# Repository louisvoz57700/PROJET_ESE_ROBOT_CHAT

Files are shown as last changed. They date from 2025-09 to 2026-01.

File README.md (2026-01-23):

# 🤖 PROJET_ESE_ROBOT_CHAT

Bienvenue dans le repository de notre projet de 3ème année.  
Ce projet a pour but de concevoir et développer un **robot intelligent** capable d’interagir et d’échanger de manière autonome dans le cadre du jeu "Chat".  

---

## 👥 Membres de l’équipe

- [Louis Vozzola](https://github.com/louisvoz57700)  
- [Antoine LEMARIGNIER](https://github.com/LEMARIGNIER-Antoine)  
- [Thomas TERLINDEN](https://github.com/TTrld)
- [Kenny Saint Fleur](https://github.com/Kennystflr)  

---

## 📁 Structure du projet

Ce dépôt est organisé de la manière suivante :

- `Datasheet/` : Contient les **documents techniques** des composants électroniques (datasheets, notes d’application, documents de référence).  

- `Hardware/` : Contient la **conception matérielle**, incluant les projets KiCad (schémas, PCB, librairies locales) et fichiers liés à la fabrication (impression 3D).  

- `IMG/` : Contient toutes les **images et illustrations** du projet (schémas explicatifs, rendus PCB, photos du prototype, captures pour la documentation).  

- `Software/` : Contient le **code source / firmware**, y compris les projets STM32CubeIDE, le code embarqué (C/C++) et les scripts utilitaires éventuels.

---

## 📅 Organisation

- **Phase 1 (Début Septembre)** : Étude et conception
Nous avons étudié les possibilités et choisis d'adopter [deux solutions de pcb](./Hardware).
- **Phase 2 (Mi-Septembre à Mi-Octobre)** : Développement hardware & software
Nous avons réalisé le developpement hardware du projet en 3 semaines et nous avons ensuite concentré nos efforts sur le développement des blocks individuels du software embarqué.
- **Phase 3 (Décembre)** : Intégration et tests
Nous avons intégrés et adaptés les différents blocks des capteurs et actionneurs dans le [code résultant](./Software). 
- **Phase 4  (Janvier)** : Présentation finale
Malgré le dépqart en double-dipplome de la majorité de l'équipe, nous avons travaillé a obtenir des extraits vidéos montrant le résultat de nos travaux.  

---

## 🛠️ Technologies utilisées (prévisionnel)

- **Langages** : Python / C  
- **Matériel** : STM32 / VL053 / LIDAR
- **Fabrication** : JLCPCB / Imprimante 3D FDM / Fusion 360

---
## Résultats :

### Vidéo finale du chat en jeu :
https://github.com/user-attachments/assets/e0ab9da4-8b44-4d55-9d14-98a5d518202f

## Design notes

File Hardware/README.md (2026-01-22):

# 🛠️ Hardware – README

Bienvenue dans ce README dédié à **l’ensemble de la partie hardware** du projet.

---

## 🧩 Architecture matérielle

Pour notre projet, nous avons conçu **deux PCB distincts**, chacun répondant à un objectif précis :

- **[Bluetooth WB55](./WB55)**  
  Carte principale intégrant le microcontrôleur **STM32WB55** et l’ensemble de la chaîne Bluetooth Low Energy.

- **[Mainboard G431](./G431)**  
  Carte secondaire conçue comme solution de secours, destinée à prendre le relais en cas de défaillance du PCB Bluetooth.

Notre stratégie de développement s’est appuyée sur la conception d’un **module Bluetooth dédié**, incluant les éléments les plus critiques du design RF, notamment l’antenne et ses réseaux d’adaptation.  
En parallèle, par souci de robustesse et de gestion des risques, une **Mainboard alternative** a été développée pour garantir la continuité du projet.

Le module Bluetooth s’étant révélé **fonctionnel et performant dès la première mise sous tension**, nous avons validé cette architecture et décidé de **ne pas retenir la solution de repli** basée sur la Mainboard.

---

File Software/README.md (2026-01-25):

## PCB_A : version WB55 (celui sur le robot)

### Partie FreeRTOS
La section se trouve ici : [code](PCB_A/jeu_chat/PCB_BLE)

#### Fonctionnement : 
Notre code fonctionne avec FreeRTOS et nous avons décidé de le faire fonctionner grâce à 4 tâches : [disponible ici](PCB_A/jeu_chat/PCB_BLE/Core/Src/tasks)

 * task_FSM.c : c'est notre machine à état.   (attr.priority   = BASE_PRIO + 4;)
 * task_comm.c : utilisé pour l'écran, l'écran passe de l'image d'une souris à celle d'un chat suivant le mode de jeu choisis. (attr.priority   = BASE_PRIO +  1;)
 * task_control.c : mode chat, définit la façon pour attraper la souris. (Mode souris ici fonctionne, est décrite dans task_FSM, on lui fait faire seulement un carré par manque de temps). (attr.priority   = BASE_PRIO + 5;)
 * task_sensor.c : Lidar + tof ( lidar : attr.priority   = BASE_PRIO + 3; et tof : attr.priority   = BASE_PRIO + 2;)

## Organigramme de décision
Organigramme de decision

Concernant la gestion du jeu en mode souris, par manque de temps nous avons du opter pour un simple carré constituant une pattern de fuite.

### Capteurs et actionneurs : 
La logique de tous nos capteurs se retrouvent ici : [disponible ici](PCB_A/jeu_chat/PCB_BLE/Core/Src/capteurs)

Vidéo du robot suivant une cible avec le lidar :
https://github.com/user-attachments/assets/37d389ab-2c22-427e-961a-3d2abfaa119d

La logique de tous nos actionneurs se retrouvent ici : [disponible ici](PCB_A/jeu_chat/PCB_BLE/Core/Src/actionneurs)

Notre odométrie et notre PID se trouvent dans le fichier suivant : [odométrie + PID](PCB_A/jeu_chat/PCB_BLE/Core/Src/actionneurs/moteur.c)
Dans le même fichier, on y retrouvera 2 fonctions utiles à nos déplacements Robot_Translation et Robot_Rotation qui peuvent être appelées et qui nous servent pour la chasse ainsi que pour la fuite.

Test du carré sur odométrie suffisante : 
https://github.com/user-attachments/assets/7094cc9a-a563-437a-8e9e-69ce3a43d382

--- 

### Partie Bluetooth
La section Software/PCB_A/Preuve_BLE/BLE est la section de notre code de preuve de notre antenne Bluetooth intégrée à notre PCB. Tout fonctionne ! Notre code est ici :[code](PCB_A/Preuve_BLE/BLE)

Ce qu'on a fait : on a suivi la vidéo suivante : STM32 Bluetooth Firmware Tutorial (Bring-Up) - Phil's Lab #129

Les étapes : aller sur stm32CubeProgrammer et on upgrade les firmware, on n'oublie pas de start le wireless stack sinon on ne verra pas notre carte lors de la connexion bluetooth.

Puis sur stm32CubeIde, on va aller créer un service qui peut écrire et lire.

On rajoute une fonction pour interpréter les notifications (la fonction est ici : [custom_app.c](PCB_A/Preuve_BLE/BLE/STM32_WPAN/App/custom_app.c))

Rajoutons un message : "Hello Laurent Fiack from antonio, Louis, Kenny et thomas!", qu'on va lire sur notre téléphone pour tester la connexion.

Une fois que c'est fait, on installe sur notre téléphone l'application ST BLE toolbox. 

On se connecte sur notre carte :



puis on rejoins notre service : 



On regarde le message reçu :



La valeur hexadécimale affichée est : 

4865-6C6C-6F20-4C61-7572-656E-7420-4669-6163-6B20-6672-6F6D-2061-6E74-6F6E-69-6F2C-204C-6F75-69-732C-204B-656E-6E79-2065-7420-7468-6F6D-6173-2100

Ce qui donne en (ASCII) :

Hello Laurent Fiack from antonio, Louis, Kenny et thomas!

C'est bien le message envoyé !

### IHM

L'utilisation du bluetooth nous permet de créer une Interface Homme-Machine (IHM) nous permettant de communiquer avec le robot depuis une machine. Pour cela nous avons utilisée une page web [appBLEv1.0](PCB_A/Software_bluetooth/appBLEv1.0.html) qui peut tirer à profit l'extention BLE de Chrome (à date de janvier 2026 Chrome est le seul navigateur où cette extention existe).

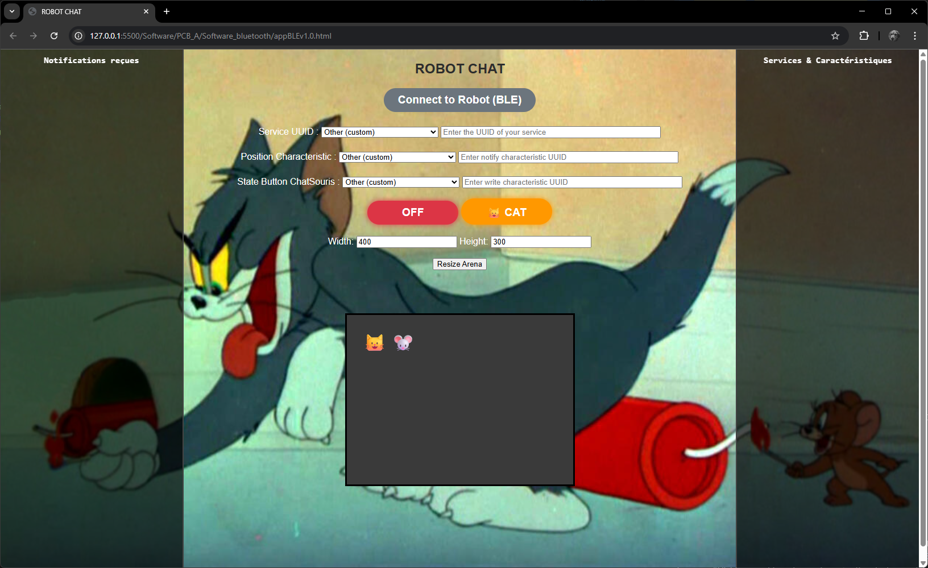
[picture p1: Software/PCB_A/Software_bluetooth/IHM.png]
IHM


Cette page html permet de se connecter au robot, d'envoyer des commandes (démarrer/arrêter, choisir le mode chat/souris) en utilisant la caractéristique écrire et de recevoir des informations (odometrie du robot et position du robot adverse) en utilisant la caractéristique notify.

Pour utiliser cette page, il suffit de l'ouvrir dans Chrome. Avant de connecter la stm32, il bien indiquer l'uuid du service, vous pourrez retrouver cette information avec l'application ST BLE toolbox comme montré dans la section précédente ou sur PC avec le logiciel [Bluetooth LE Explorer](https://apps.microsoft.com/detail/9n0ztkf1qd98) de Microsoft. 
La page web est faite de façon à ce que l'uuid du service et des caractéristiques soient modifiables et vous pouurez retrouver les uuids des services lors de la connexion.

Le projet [ble_demo](PCB_A/ble_demo) est un exemple d'utilisation de l'interface bluetooth permettant une demonstration simple de l'IHM et des caractéristiques bluetooth implémentées.

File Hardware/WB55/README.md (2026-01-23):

## 📡 PCB Bluetooth

Pour cette carte électronique, nous avons privilégié l’utilisation des composants recommandés et fournis par notre professeur, afin d’assurer **fiabilité et cohérence pédagogique**.  

Les principaux composants intégrés sont :

- **Microcontrôleur** :  
  *STM32WB55CGU*, intégrant un second cœur **Cortex-M0+** dédié à la gestion de la communication **Bluetooth Low Energy (BLE)**.

- **Drivers moteurs** :  
  *ZXBM5210*, permettant un pilotage simple et efficace des moteurs.

- **Régulateur LDO (5 V → 3,3 V)** :  
  *BU33SD5WG-TR*, utilisé pour l’alimentation du microcontrôleur.

- **Convertisseur Buck (Vbat → 5 V)** :  
  *MP1475SGJ-P*, destiné à l’alimentation des capteurs (LiDAR, ToF, mesure de courant).

- **Multiplexeur I²C** :  
  *TCA9548AMRGER*, permettant de sélectionner dynamiquement le capteur ToF avec lequel communiquer.

- **Accéléromètre** :  
  *ADXL343*, utilisé pour la détection des taps et des mouvements.

---
## Schéma de Principe


---

## 🔹 Description du PCB Bluetooth

### Section RF
La **partie droite du PCB** est dédiée à la **section RF**, avec notamment :

- Une **antenne conçue et réalisée directement sur le PCB**.  
- Un **filtre passe-bande centré sur 2,4 GHz**.  
- Un **réseau d’adaptation d’impédance** pour optimiser les performances radio et le débit maximal.

### Connecteur Bluetooth externe
Un **connecteur dédié au Bluetooth externe** permet de disposer d’une **solution de secours** si le module intégré ne fonctionne pas ou ne répond pas aux performances attendues, augmentant ainsi la **robustesse et la flexibilité** du système.

### Capteurs et moteurs
Le PCB intègre **quatre connecteurs pour les capteurs ToF**, pour détecter les obstacles à l’avant, à l’arrière et sur les côtés du robot.  
Les **deux sorties moteurs** et les **signaux des encodeurs** sont regroupés sur le **côté gauche**, facilitant l’intégration mécanique et optimisant le **routage des câbles**.

### Indicateurs de tension
Des **indicateurs 3,3 V et 5 V** permettent de vérifier rapidement le bon fonctionnement des régulateurs et simplifient les phases de **mise au point et de diagnostic**.

### Test points et conversion de tension
- La **partie droite** regroupe les **points de test**, donnant accès aux signaux principaux pour le **débogage**.  
- La **conversion de tension** est placée sur l’**autre face du PCB** (côté « chat-souris »), isolant les étages de puissance des circuits sensibles et améliorant la **lisibilité globale** de la carte.

---
## Réalisation :

<p align="center">
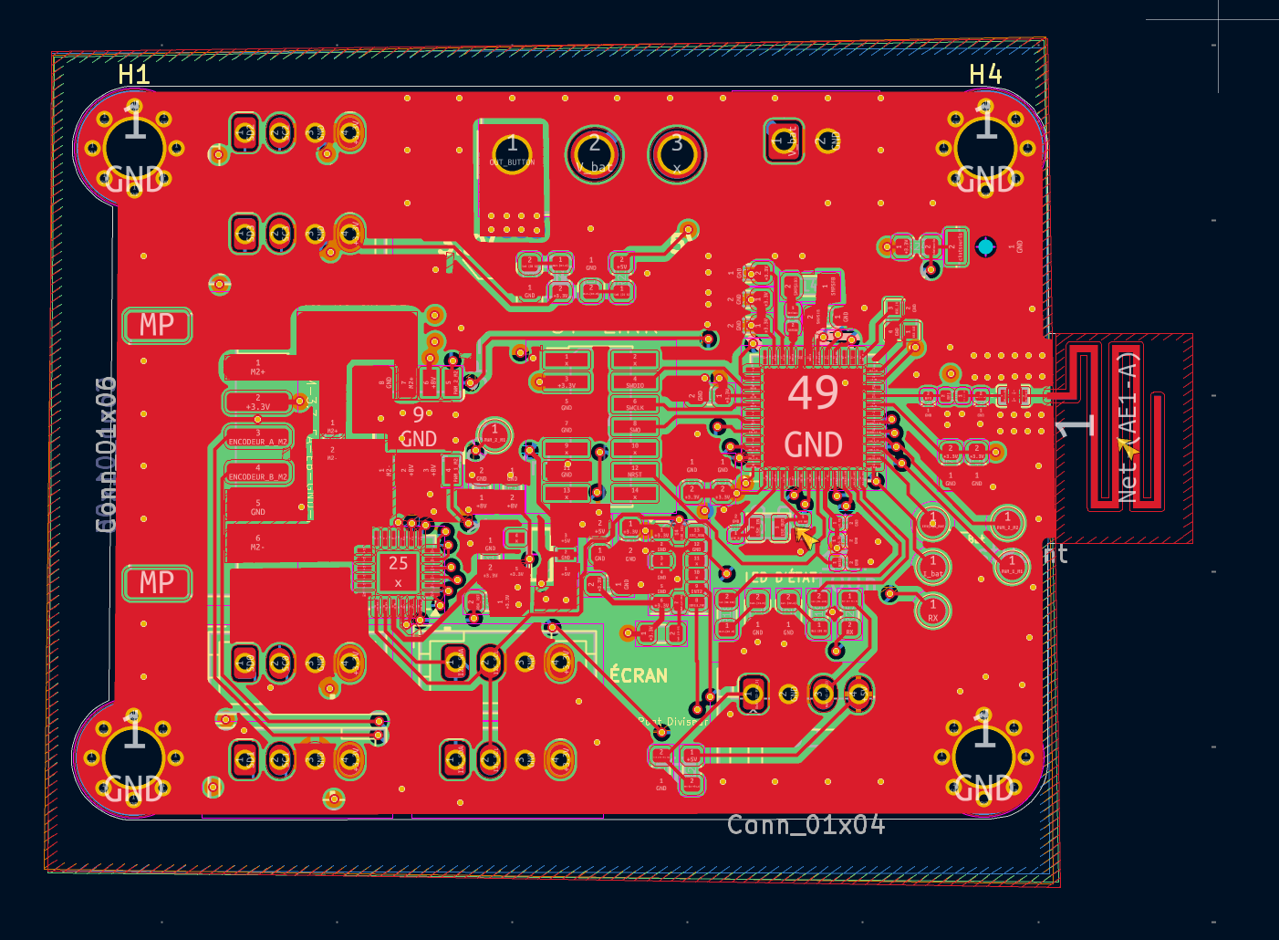
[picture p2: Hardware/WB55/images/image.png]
  
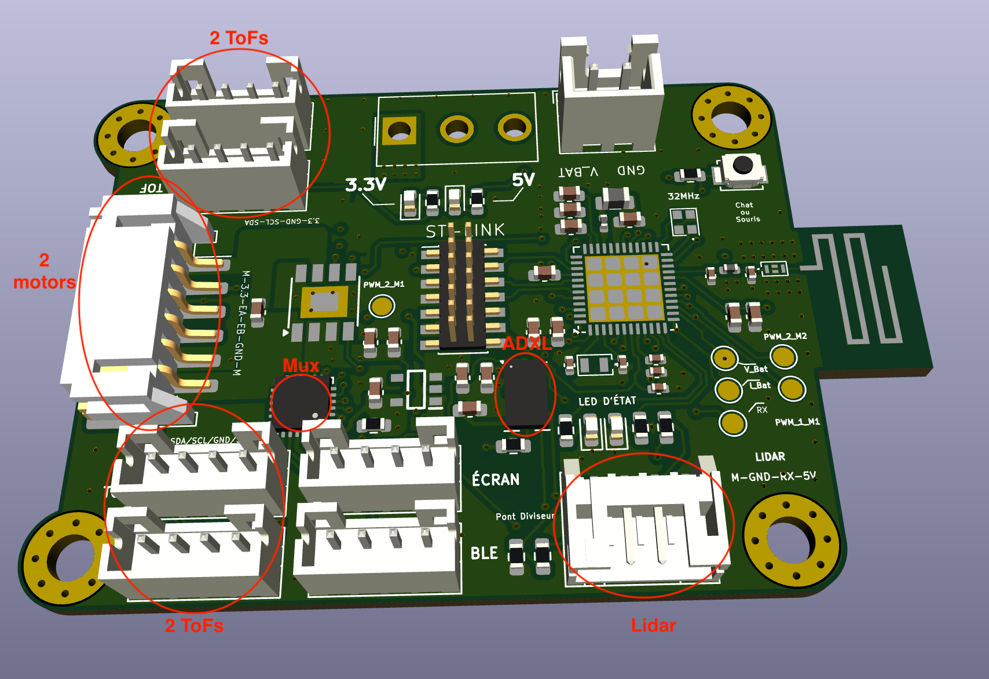
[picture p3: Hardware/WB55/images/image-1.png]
  
  
</p>

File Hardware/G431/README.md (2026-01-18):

# 🤖 Robot Chat – Carte électronique de contrôle  
## Version alternative (non embarquée sur le robot final)

## Présentation générale

Ce dépôt présente une **carte électronique de contrôle** développée dans le cadre du projet **Robot Chat**, réalisé au sein de la spécialité **ESE**.

⚠️ **Note importante**  
Le PCB documenté ici correspond à une **version alternative de la carte électronique**, différente de celle effectivement intégrée sur le robot final.  
Cette version a été conçue afin d’explorer une **architecture plus modulaire et plus riche en périphériques**, tout en respectant les mêmes contraintes fonctionnelles et temporelles que la carte embarquée.

La carte a été **entièrement conçue, routée et préparée à la validation en 4 semaines**, couvrant l’ensemble de la chaîne électronique du système robotique.

---

## 🖼️ Vue d’ensemble du PCB

### Vue 3D
> *Implantation globale des composants et contraintes mécaniques*

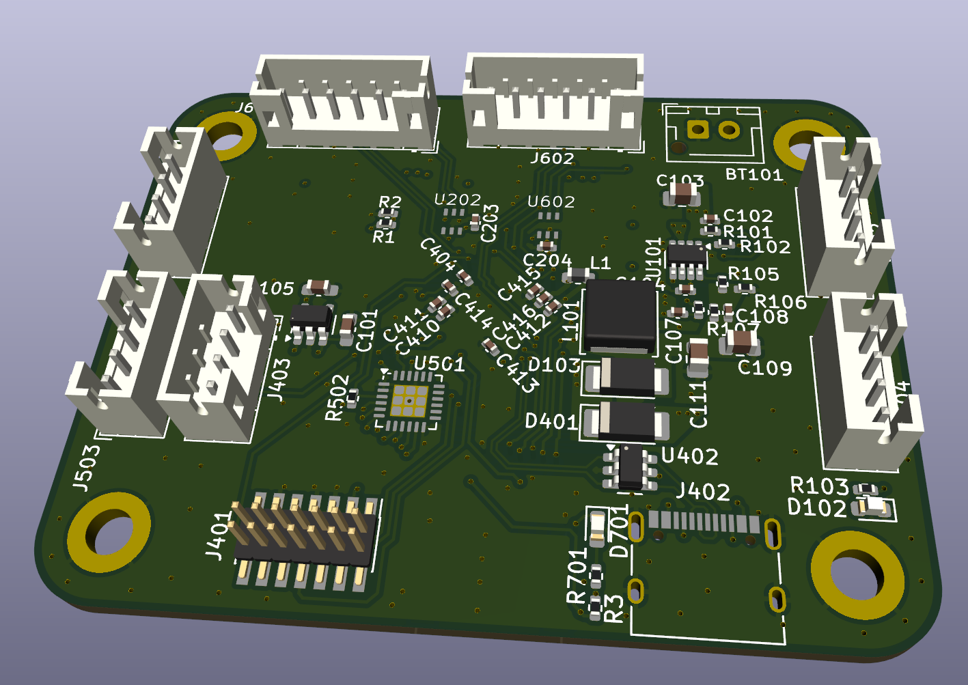
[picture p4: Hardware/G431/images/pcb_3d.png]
Vue 3D du PCB


### Faces Top & Bottom
> *Placement des composants, densité de routage et organisation des plans*

| Face Top | Face Bottom |
|---|---|
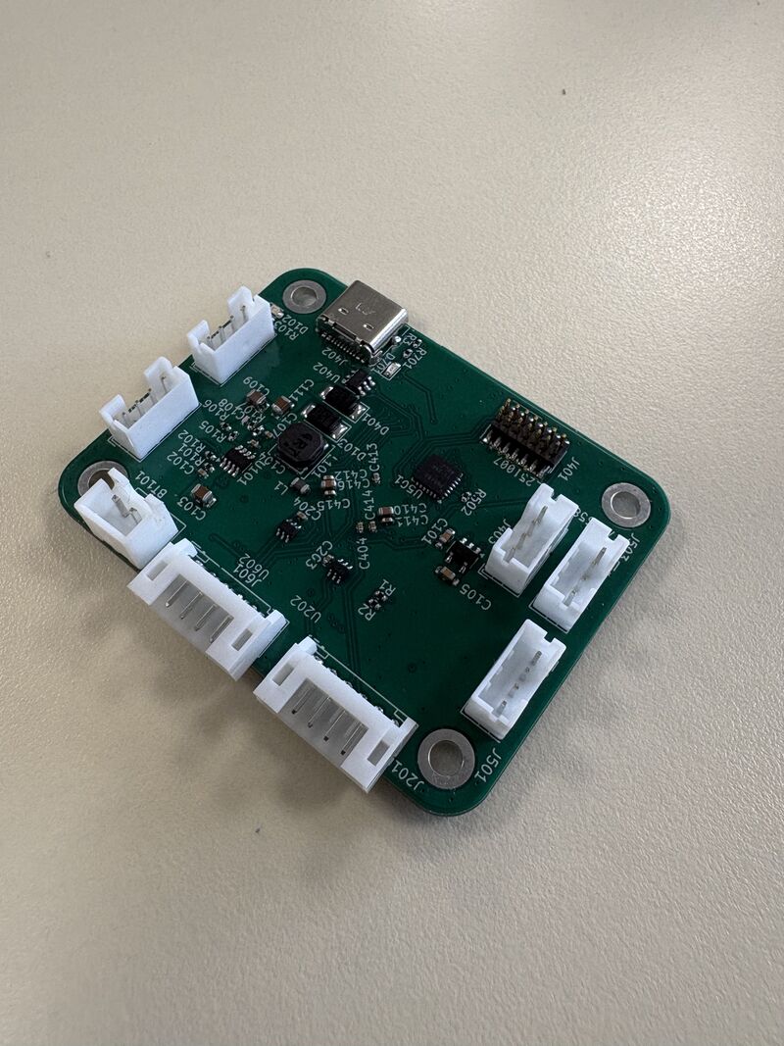
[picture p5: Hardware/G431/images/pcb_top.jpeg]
PCB Face Top
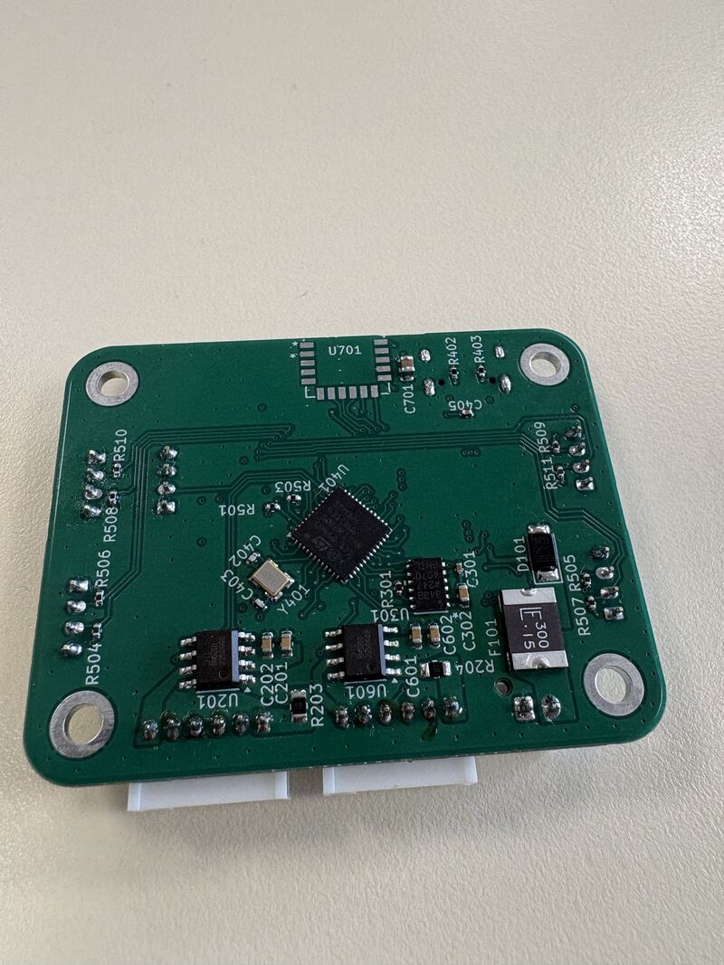
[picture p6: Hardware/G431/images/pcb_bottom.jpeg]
PCB Face Bottom
|  |  |

📌 Ces visuels permettent une lecture rapide de la complexité de la carte et de sa qualité de conception.

---

## 🧠 Architecture système

### Schematic Globale
> *Vue haut niveau des sous-systèmes et des flux de données*

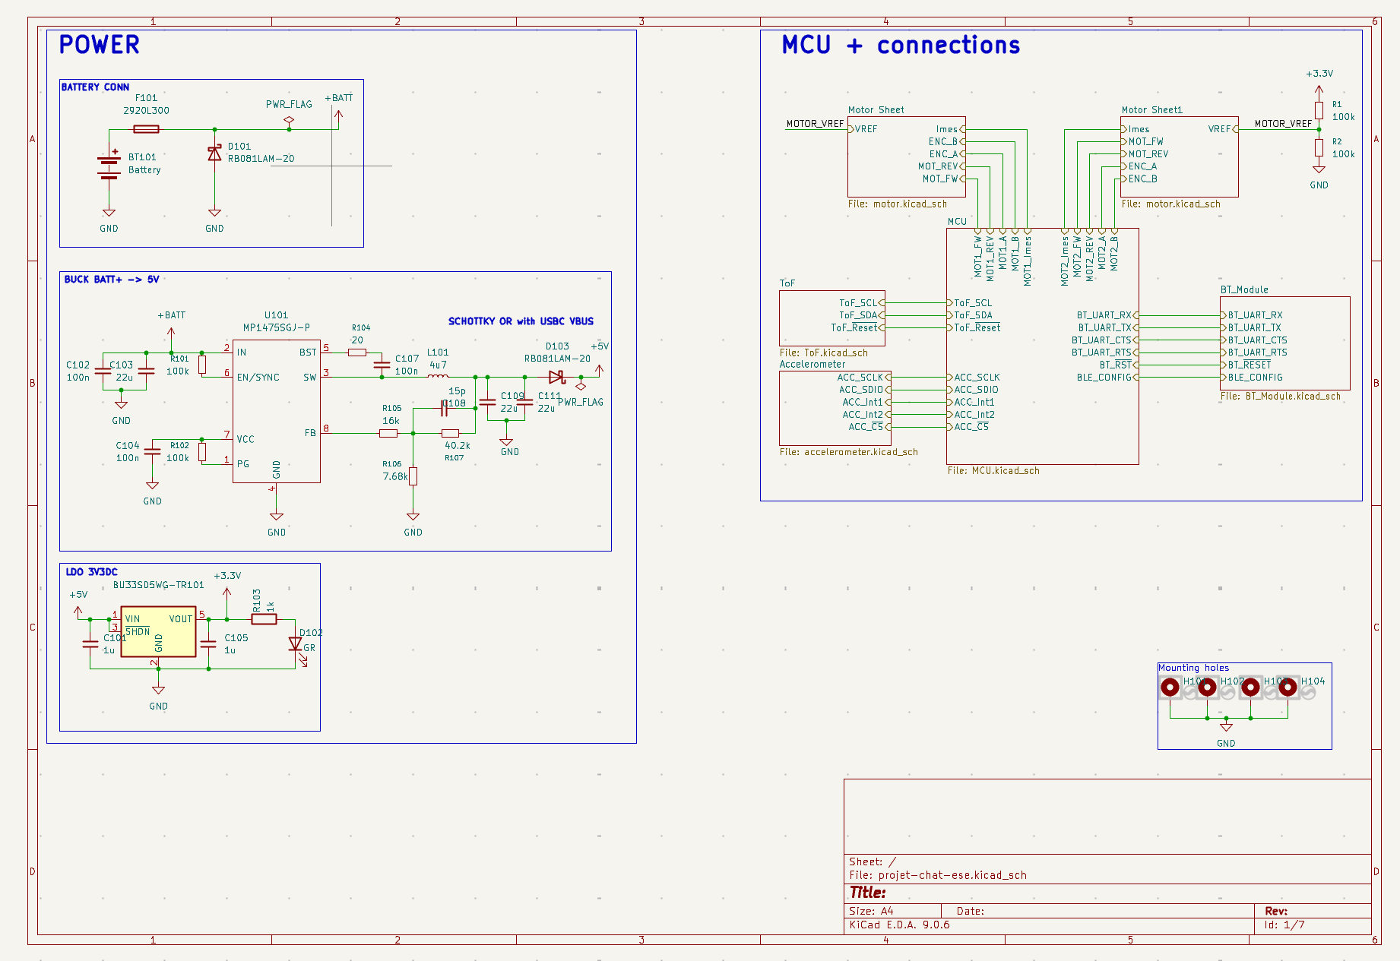
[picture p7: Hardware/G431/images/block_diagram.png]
Schema fonctionnel


La carte est organisée autour des blocs fonctionnels suivants :
- calcul et traitement temps réel,
- commande des actionneurs,
- acquisition des capteurs,
- gestion de l’alimentation.

---

## 🔌 Calcul & communication

### Microcontrôleur principal

- **STM32G431 – 170 MHz**
  - Exécution de **FreeRTOS**
  - Gestion du contrôle moteur
  - Acquisition capteurs et fusion de données
  - Communication avec l’IHM PC (UART->Bluetooth)

Le microcontrôleur centralise les tâches temps réel critiques du système.

---

## ⚙️ Commande des moteurs

- **2 drivers de moteurs DC**
- Lecture des **codeurs incrémentaux**
- **Mesure de courant** pour :
  - estimation du couple,
  - détection de surintensité,
  - sécurisation du système

L’architecture permet un contrôle précis et robuste des actionneurs.

---

## 📡 Capteurs & navigation

- **4 capteurs Time-of-Flight (ToF)**
  - détection du vide,
  - évitement d’obstacles
- **IMU (accéléromètre + gyroscope)**
  - odométrie,
  - estimation de l’état du robot
- **Lidar**
  - cartographie de l’environnement,
  - navigation autonome dans l’aire de jeu

Le placement des capteurs a été pensé pour maximiser le champ de vision et limiter les interférences.

---

## 🔋 Architecture d’alimentation

### Arbre d’alimentation
> *Stratégie de régulation et domaines de tension*

- Plusieurs rails d’alimentation régulés
- Séparation des domaines :
  - puissance moteurs,
  - logique numérique,
  - capteurs sensibles
- Filtrage et découplage adaptés à un système embarqué mobile

---

## 🧱 Conception PCB

- **PCB 4 couches**
  - Signal
  - Plan de masse continu
  - Plan d’alimentation
  - Signal
- Séparation analogique / numérique
- Routage optimisé pour :
  - intégrité du signal,
  - réduction du bruit,
  - facilité de mise au point (bring-up)

---

## 👥 Équipe & encadrement

Projet réalisé par :
- Antoine Lemarignier  
- Louis Vozzola  
- Thomas Terlinden  
- Kenny Saint Fleur

Encadrement :
- **Laurent Fiack**
- **Nicolas Papazoglou**  
École nationale supérieure de l’Électronique et de ses Applications (ENSEA)

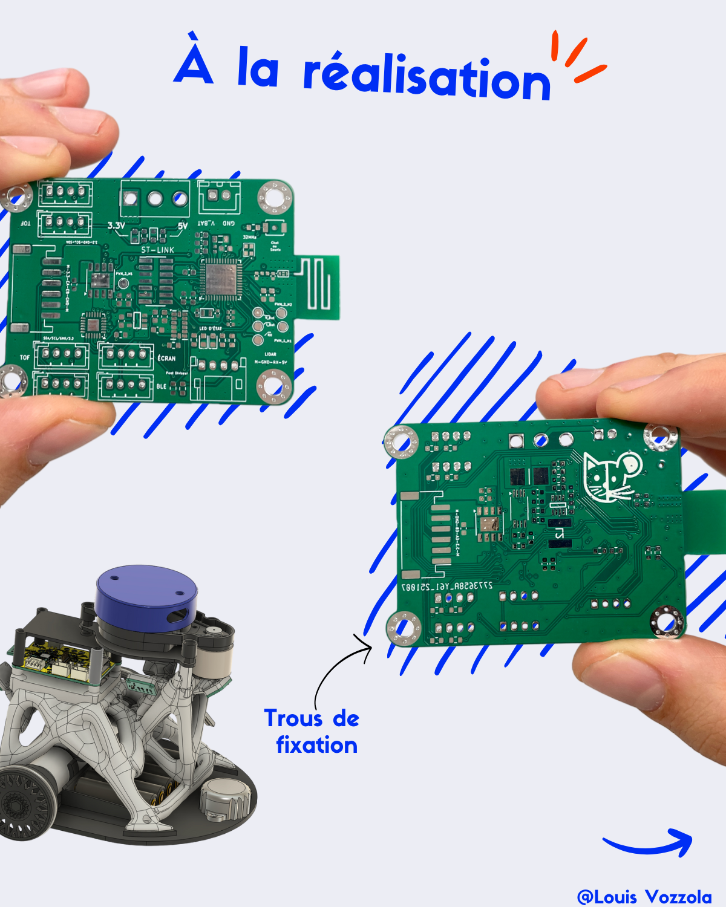
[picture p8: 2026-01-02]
IMG/PCB_BLE2.PNG

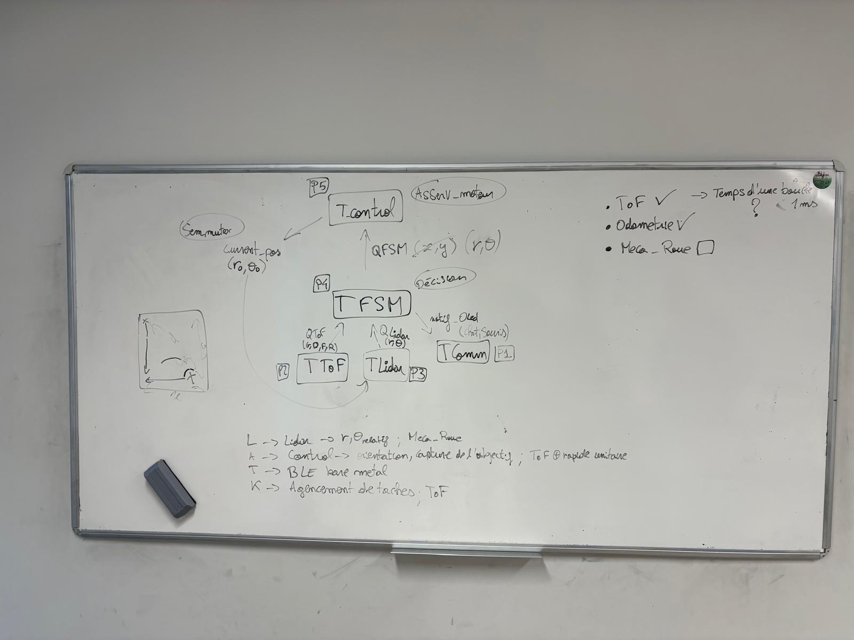
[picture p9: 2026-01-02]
IMG/Strategy.JPG

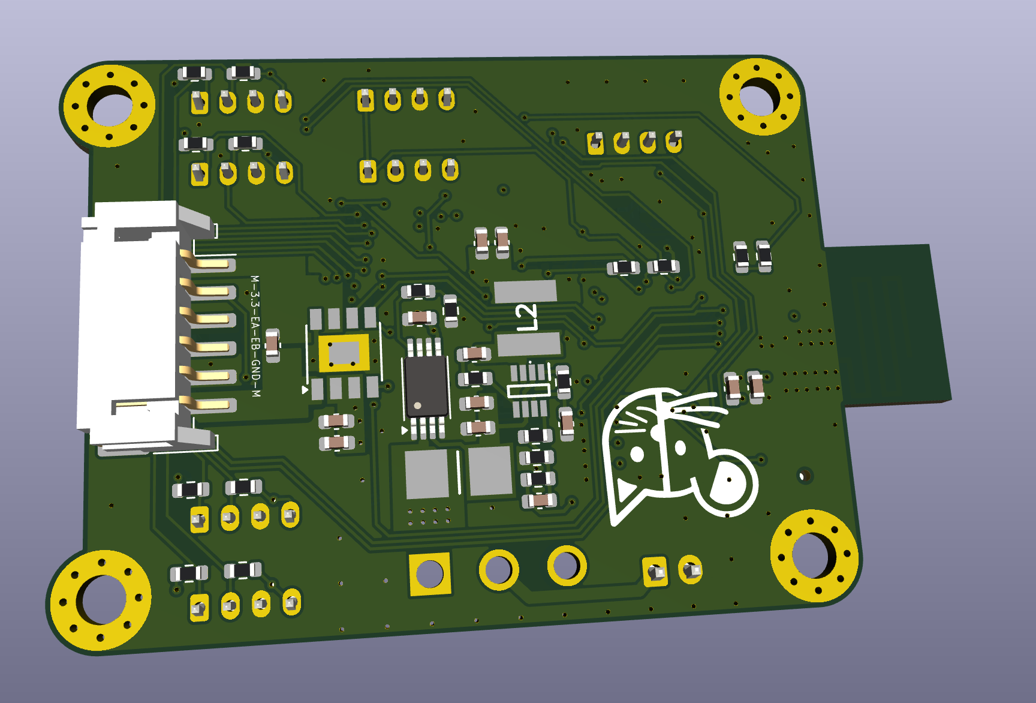
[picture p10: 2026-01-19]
IMG/PCB_BLE_Kicad_3D_Down.png

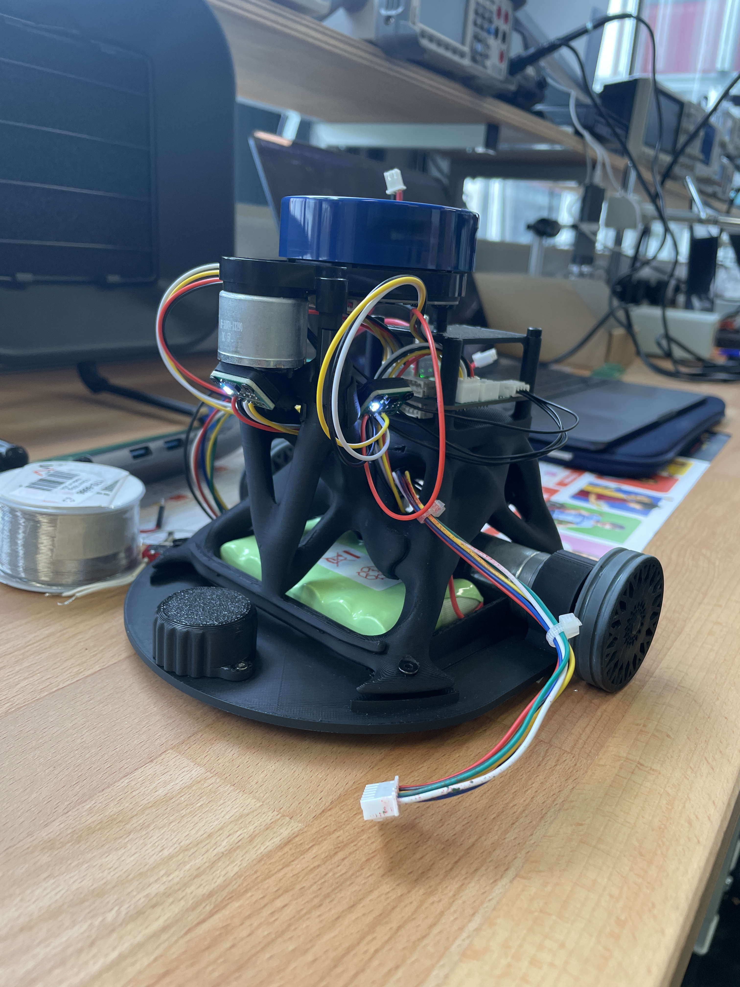
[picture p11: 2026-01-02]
IMG/robot_2.JPG

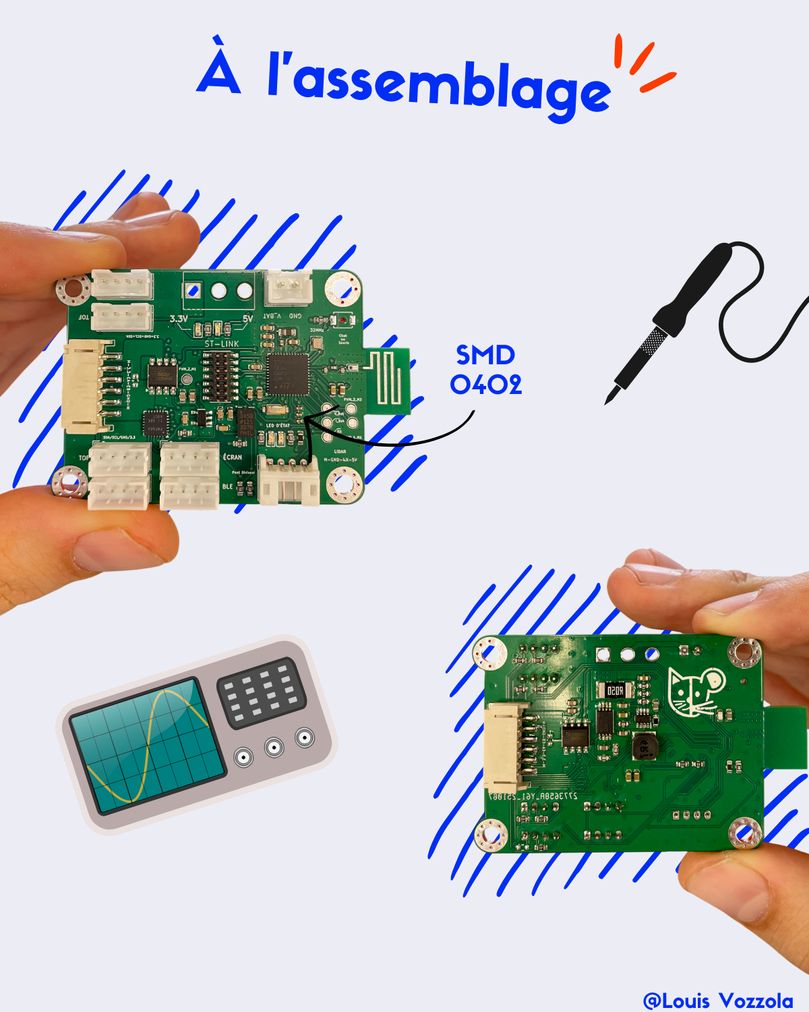
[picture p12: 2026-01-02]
IMG/PCB_BLE3.PNG

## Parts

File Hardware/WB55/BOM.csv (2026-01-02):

Id | Designator | Footprint | Quantity | Designation | Supplier and ref
1 | C43,C33,C32,C39,C12,C29,C30 | C_0603_1608Metric | 7 | 4.7u
2 | J2 | JST_PH_S4B-PH-K_1x04_P2.00mm_Horizontal | 1 | Conn_01x04
3 | AE1 | 2.4GHz BLE | 1 | Antenna
4 | J14,J11 | JST_PH_S6B-PH-SM4-TB_1x06-1MP_P2.00mm_Horizontal | 2 | Conn_01x06
5 | SW2 | SW_SPST_B3U-1000P-B | 1 | SW_SPST
6 | C1 | C_0402_1005Metric | 1 | 10n
7 | R19,R22,R23,R18,R24,R16,R17 | R_0603_1608Metric | 7 | 5k
8 | C40 | C_0402_1005Metric | 1 | 0p3
9 | C13,C14 | C_0402_1005Metric | 2 | 13p
10 | U4 | Texas_RGE0024C_VQFN-24-1EP_4x4mm_P0.5mm_EP2.1x2.1mm | 1 | TCA9548AMRGER
11 | C15,C16,C37,C31 | C_0603_1608Metric | 4 | 1u
12 | TP7,TP9,TP2,TP4,TP1,TP5 | TestPoint_Pad_D1.5mm | 6 | TestPoint
13 | C41 | C_0402_1005Metric | 1 | 0p8
14 | J9 | JST_XH_B2B-XH-A_1x02_P2.50mm_Vertical | 1 | Conn_01x02_Pin
15 | J4,J3,J8,J5,J7,J6 | JST_PH_B4B-PH-K_1x04_P2.00mm_Vertical | 6 | Conn_01x04
16 | D2,D1,D4,D3 | LED_0603_1608Metric | 4 | LED
17 | L3 | L_0402_1005Metric | 1 | 10n
18 | R26,R27,R33 | R_0603_1608Metric | 3 | 2k
19 | C8,C38,C6,C7,C11,C5,C9 | C_0603_1608Metric | 7 | 100n
20 | C2 | C_0402_1005Metric | 1 | 1u
21 | J1 | PinHeader_2x07_P1.27mm_Vertical_SMD | 1 | Conn_ST_STDC14
22 | IC4,IC3 | Diodes_SO-8EP | 2 | ZXBM5210-SP-13
23 | U5 | SSOP-5 | 1 | BU33SD5WG-TR
24 | FL1 | DLF162500LT5028A1 | 1 | DLF162500LT-5028A1
25 | R31,R30 | R_0603_1608Metric | 2 | 10k
26 | U1 | QFN-48-1EP_7x7mm_P0.5mm_EP5.6x5.6mm | 1 | STM32WB55CGUx
27 | R25 | R_0603_1608Metric | 1 | 100
28 | Y2 | Murata 32MHz | 1 | Crystal_GND24_Small
29 | C34 | C_0603_1608Metric | 1 | 470n
30 | C42 | C_0402_1005Metric | 1 | 100n
31 | L5 | L_0402_1005Metric | 1 | 2n7
32 | U3 | LGA-14_3x5mm_P0.8mm_LayoutBorder1x6y | 1 | ADXL343
33 | X1 | ABS06N32768kHzT | 1 | 32kHz758
34 | SW1 | SW_Wurth_WS-TOTV_472121020311 | 1 | SW_Wurth
35 | L4 | L_0805_2012Metric | 1 | 10u
36 | C36,C24,C22,C35,C25 | C_0603_1608Metric | 5 | 0.1u
37 | C28 | C_0603_1608Metric | 1 | 15p
38 | L2 | 74404054068 | 1 | 4.7u
39 | R11 | R_0603_1608Metric | 1 | 13k
40 | R9 | R_0603_1608Metric | 1 | 16k
41 | R2,R3,R21,R1,R5,R20,R4,R28,R6,R29 | R_0603_1608Metric | 10 | 4.7k
42 | C23,C21,C27 | C_0603_1608Metric | 3 | 22u
43 | R12 | R_0603_1608Metric | 1 | 100k
44 | C10 | C_0603_1608Metric | 1 | 100p
45 | U2 | TSSOP-8_4.4x3mm_P0.65mm | 1 | INA240A1PW
46 | IC2 | TSOT 23-8 | 1 | MP1475SGJ-P
47 | R15 | R_6431 | 1 | 50m
48 | R10 | R_0603_1608Metric | 1 | 40.2k
49 | R32 | R_0603_1608Metric | 1 | 1k
50 | R8 | R_0603_1608Metric | 1 | 20

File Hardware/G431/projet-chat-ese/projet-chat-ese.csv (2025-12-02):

Id | Référence | Empreinte | Quantité | Désignation | Fournisseur et réf
1 | C111,C103,C109 | C_0805_2012Metric | 3 | 22u
2 | U501 | VQFN-24-1EP_4x4mm_P0.5mm_EP2.45x2.45mm | 1 | TCA9548APWR
3 | J501,J503,J502,J504 | JST_PH_B4B-PH-K_1x04_P2.00mm_Vertical | 4 | Conn_01x04
4 | C204,C203,C412,C413,C102,C107,C415,C414,C411,C104,C405,C301 | C_0402_1005Metric | 12 | 100n
5 | C416,C410 | C_0402_1005Metric | 2 | 4u7
6 | J403 | JST_PH_B4B-PH-K_1x04_P2.00mm_Vertical | 1 | UART
7 | R107 | R_0402_1005Metric | 1 | 40.2k
8 | R701 | R_0402_1005Metric | 1 | 330
9 | D701 | LED_0603_1608Metric | 1 | LED
10 | L1 | L_0603_1608Metric | 1 | 39n
11 | C108 | C_0402_1005Metric | 1 | 15p
12 | R101,R102,R3,R1,R2 | R_0402_1005Metric | 5 | 100k
13 | C105,C101 | C_0603_1608Metric_Pad1.08x0.95mm_HandSolder | 2 | 1u
14 | BU33SD5WG-TR101 | SOT-23-5 | 1 | LM1117DT-3.3
15 | L101 | L_APV_ANR5020 | 1 | 4u7
16 | U202,U602 | SC70-6 | 2 | NCS199A3RSQT2G
17 | C404 | C_0402_1005Metric | 1 | 10n
18 | R104 | R_0402_1005Metric | 1 | 20
19 | J402 | USB_C_Receptacle_XKB_U262-16XN-4BVC11 | 1 | USB_C_Receptacle_USB2.0_16P
20 | J401 | PinHeader_2x07_P1.27mm_Vertical_SMD | 1 | Conn_ST_STDC14
21 | U101 | TSOT-23-8 | 1 | MP1475SGJ-P
22 | D103,D401,D101 | D_SOD-128 | 3 | RB081LAM-20
23 | R103 | R_0402_1005Metric | 1 | 1k
24 | R502,R511,R509,R508,R510,R506,R504,R501,R507,R503,R505 | R_0402_1005Metric | 11 | 4k7
25 | D102 | LED_0603_1608Metric | 1 | GR
26 | U402 | SOT-23-6 | 1 | USBLC6-2SC6
27 | R106 | R_0402_1005Metric | 1 | 7.68k
28 | BT101 | JST_XH_B2B-XH-AM_1x02_P2.50mm_Vertical | 1 | Battery
29 | J201,J601 | JST_PH_B6B-PH-K_1x06_P2.00mm_Vertical | 2 | Conn_01x06_Socket
30 | R105 | R_0402_1005Metric | 1 | 16k
31 | C402 | C_0402_1005Metric | 1 | 12p
32 | U601,U201 | SOIC-8-1EP_3.9x4.9mm_P1.27mm_EP2.29x3mm | 2 | ZXBM5210-SP-13
33 | C302,C602,C201,C601,C202 | C_0603_1608Metric | 5 | 1u
34 | Y401 | SMD 3225 | 1 | MCSJK-7U-16.00-10-30-80-B-30
35 | R204,R203 | R_0805_2012Metric | 2 | 10m
36 | U701 | BM71BLES1FC2_MCH | 1 | BM71BLES1FC2-0B04AA
37 | R403,R402 | R_0402_1005Metric | 2 | 5k1
38 | C403 | C_0402_1005Metric | 1 | 10p
39 | U301 | LGA_CC-14-1_ADI | 1 | ADXL343BCCZ-RL
40 | U401 | QFN-48-1EP_7x7mm_P0.5mm_EP5.6x5.6mm | 1 | STM32G431CBUx
41 | C701 | C_0805_2012Metric | 1 | 10u
42 | R301 | R_0402_1005Metric | 1 | 10k
43 | F101 | 2920L300 | 1 | 2920L300

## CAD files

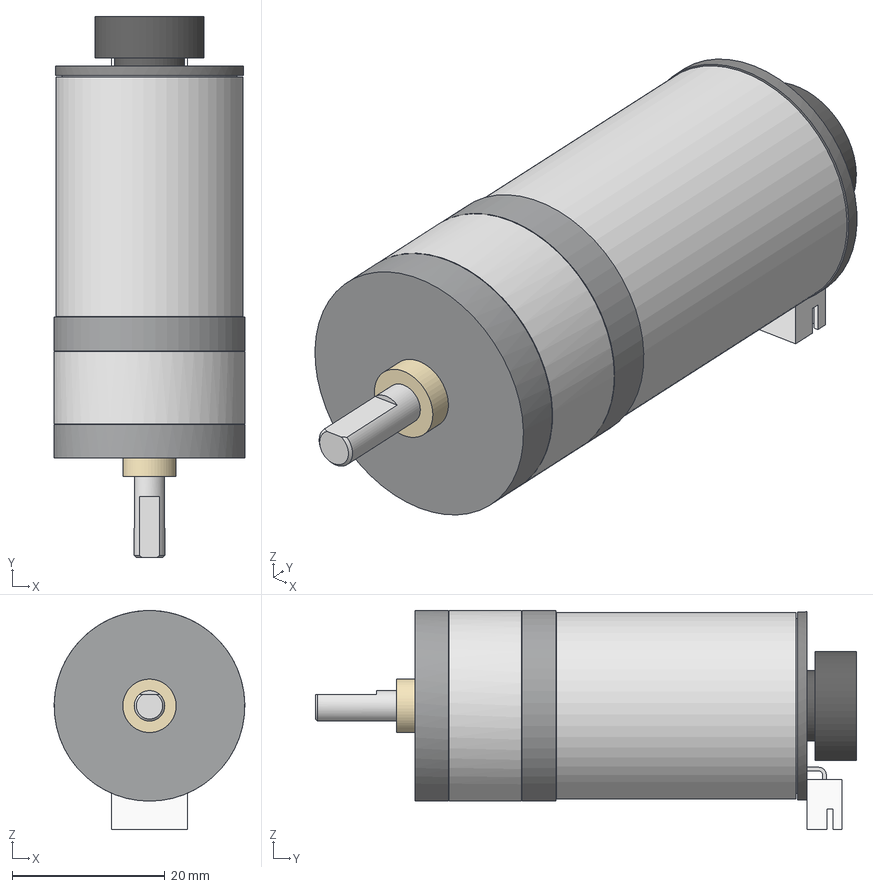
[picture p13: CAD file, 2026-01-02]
Hardware/Mecanic/FIT0520(motor).stp
25.0 x 71.0 x 28.7 mm

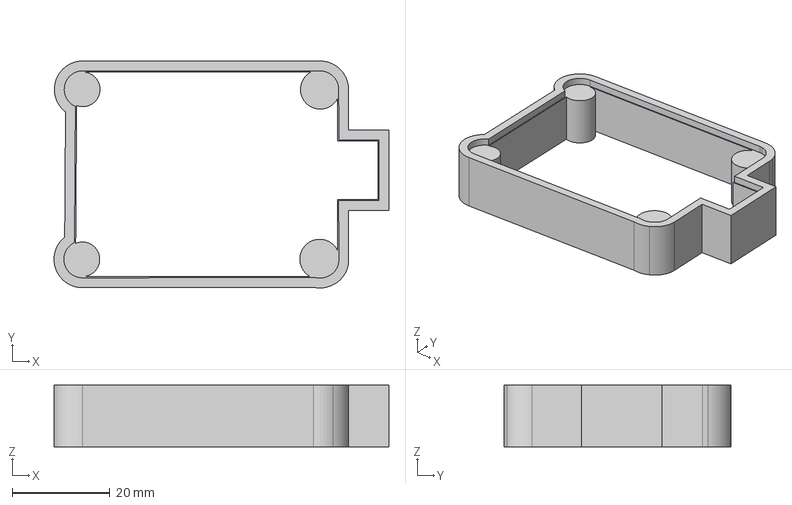
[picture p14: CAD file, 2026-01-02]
Hardware/WB55/support_PCB.step
68.5 x 46.4 x 12.6 mm

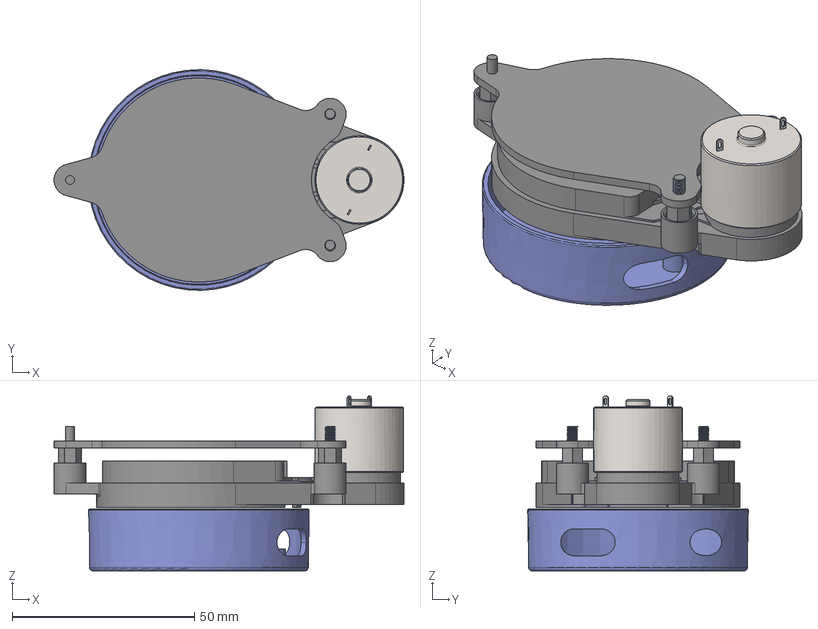
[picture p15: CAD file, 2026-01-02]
Hardware/Mecanic/LIDAR.step
96.0 x 60.5 x 48.0 mm

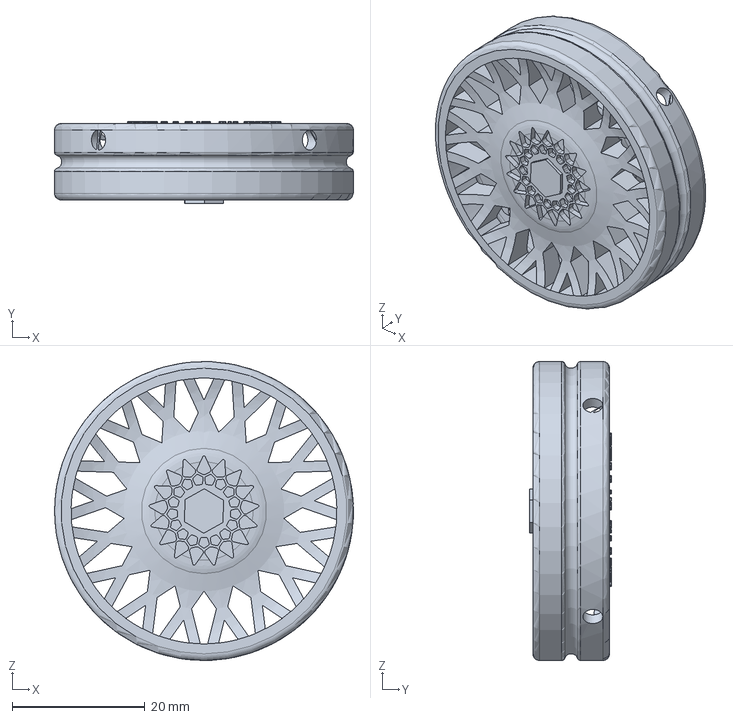
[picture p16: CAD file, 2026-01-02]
Hardware/Mecanic/wheel.step
45.0 x 12.3 x 45.0 mm

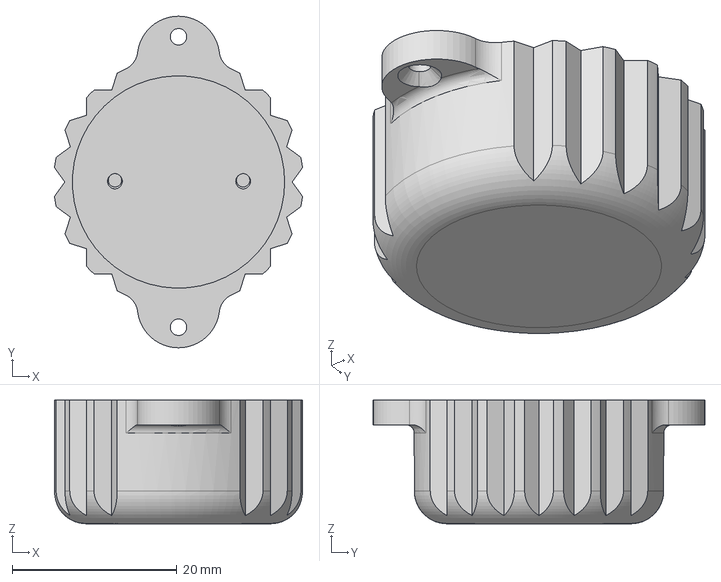
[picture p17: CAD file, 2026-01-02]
Hardware/Mecanic/bowl_support.step
30.1 x 40.2 x 15.0 mm

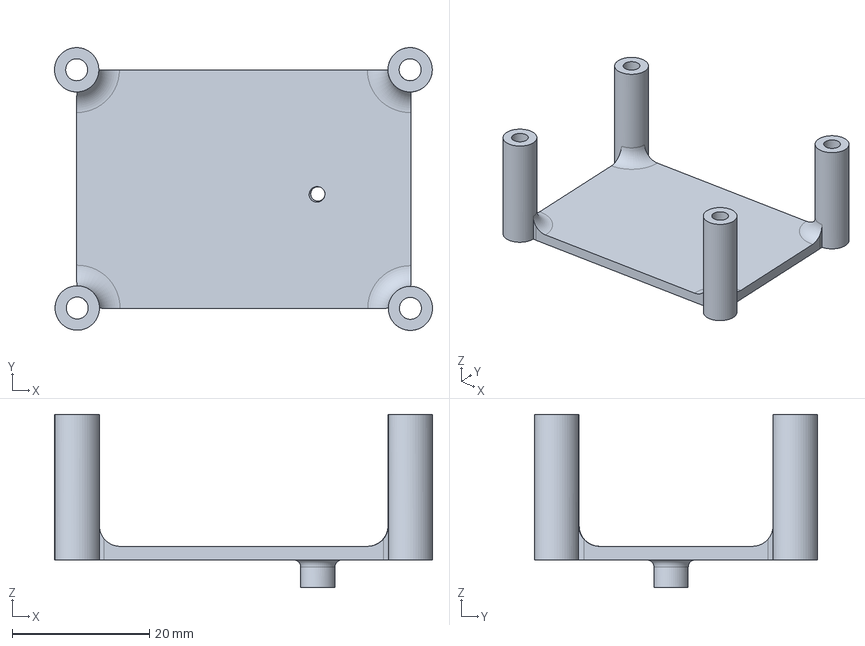
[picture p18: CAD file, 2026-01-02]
Hardware/Mecanic/up_body2.step
55.0 x 41.2 x 25.2 mm

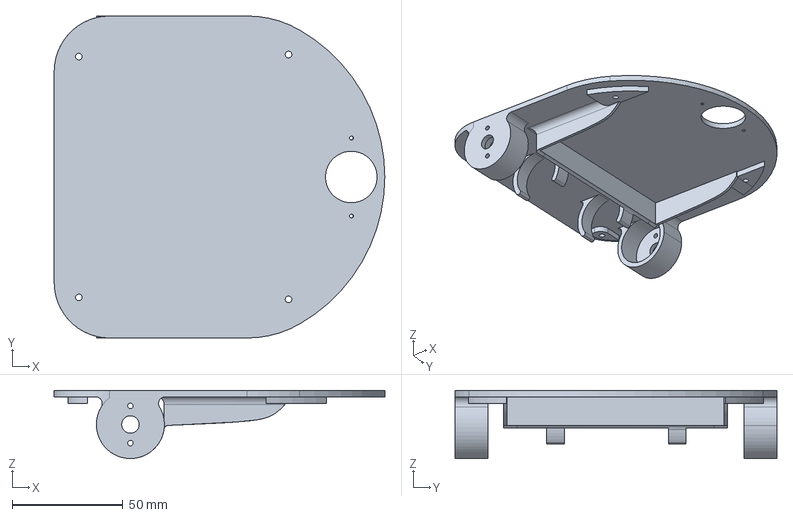
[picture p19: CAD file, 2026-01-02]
Hardware/Mecanic/down_body.step
149.2 x 145.3 x 30.7 mm

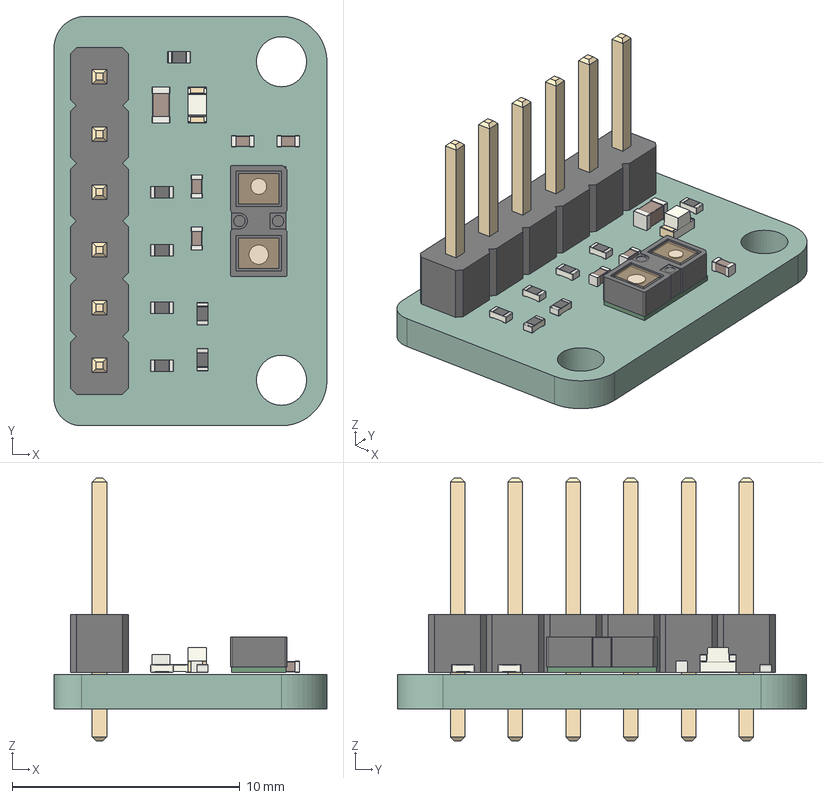
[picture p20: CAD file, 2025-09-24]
Hardware/Mecanic/vl53l0(TOF).step
12.0 x 18.0 x 11.5 mm
C_0402_1005Metric x 4
R_0402_1005Metric x 7
PinHeader_1x06_P2.54mm_Vertical
LED_0603_1608Metric
C_0603_1608Metric
ST_VL53L1x
vl53l0_breakout_PCB

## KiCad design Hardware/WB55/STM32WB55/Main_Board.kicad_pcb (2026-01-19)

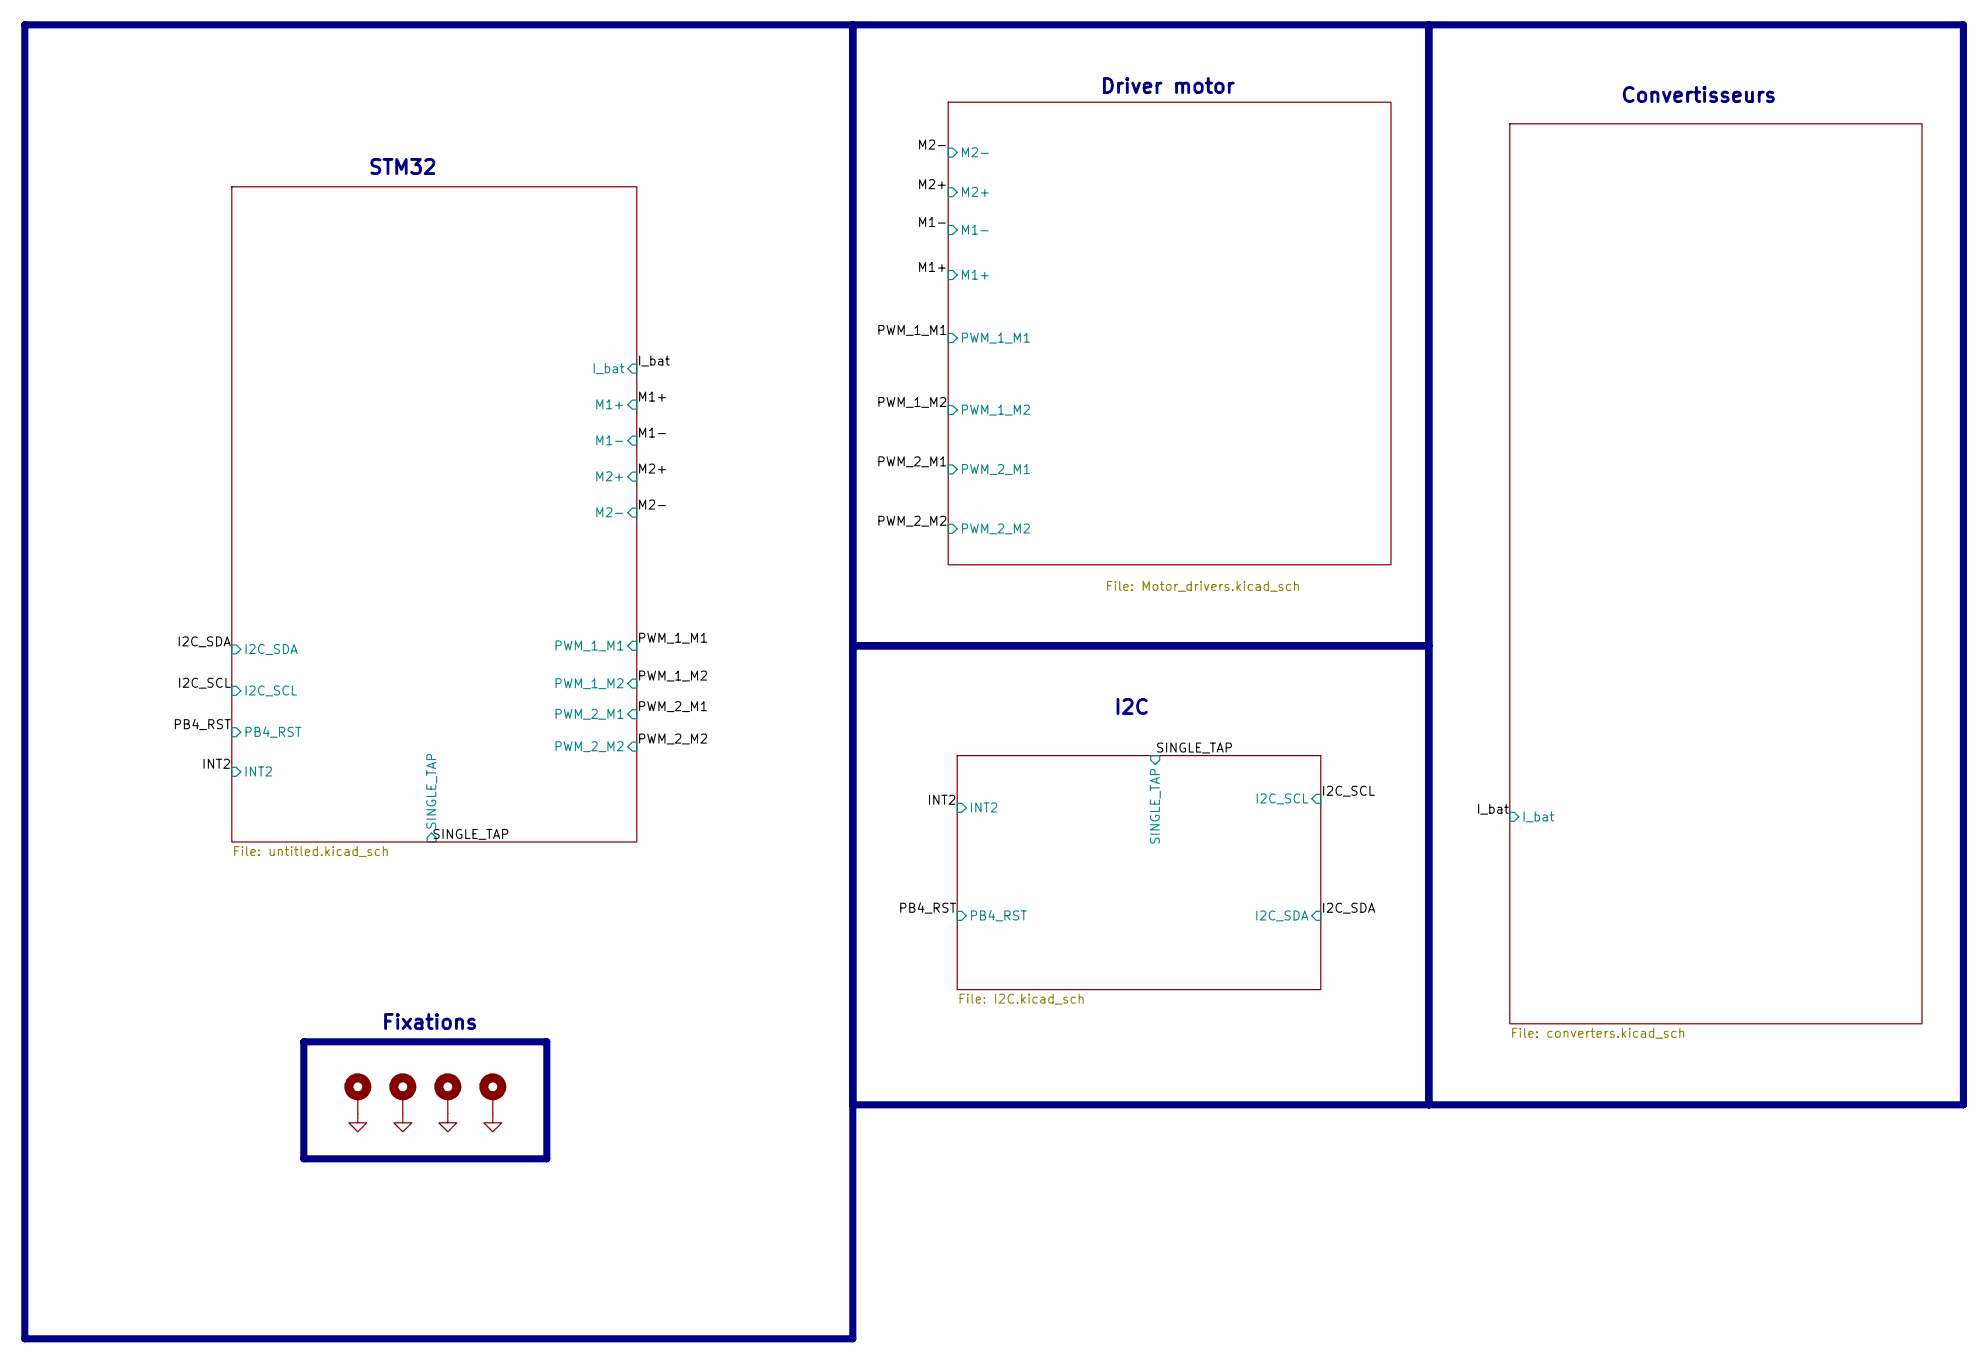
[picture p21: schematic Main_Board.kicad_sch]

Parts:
H1, H2, H3, H4: MountingHole_Pad; MountingHole_3.2mm_M3_Pad_Via

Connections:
GND: H1.1, H2.1, H3.1, H4.1; also elsewhere on the board

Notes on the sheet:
Convertisseurs
I2C
STM32
Fixations
Driver motor

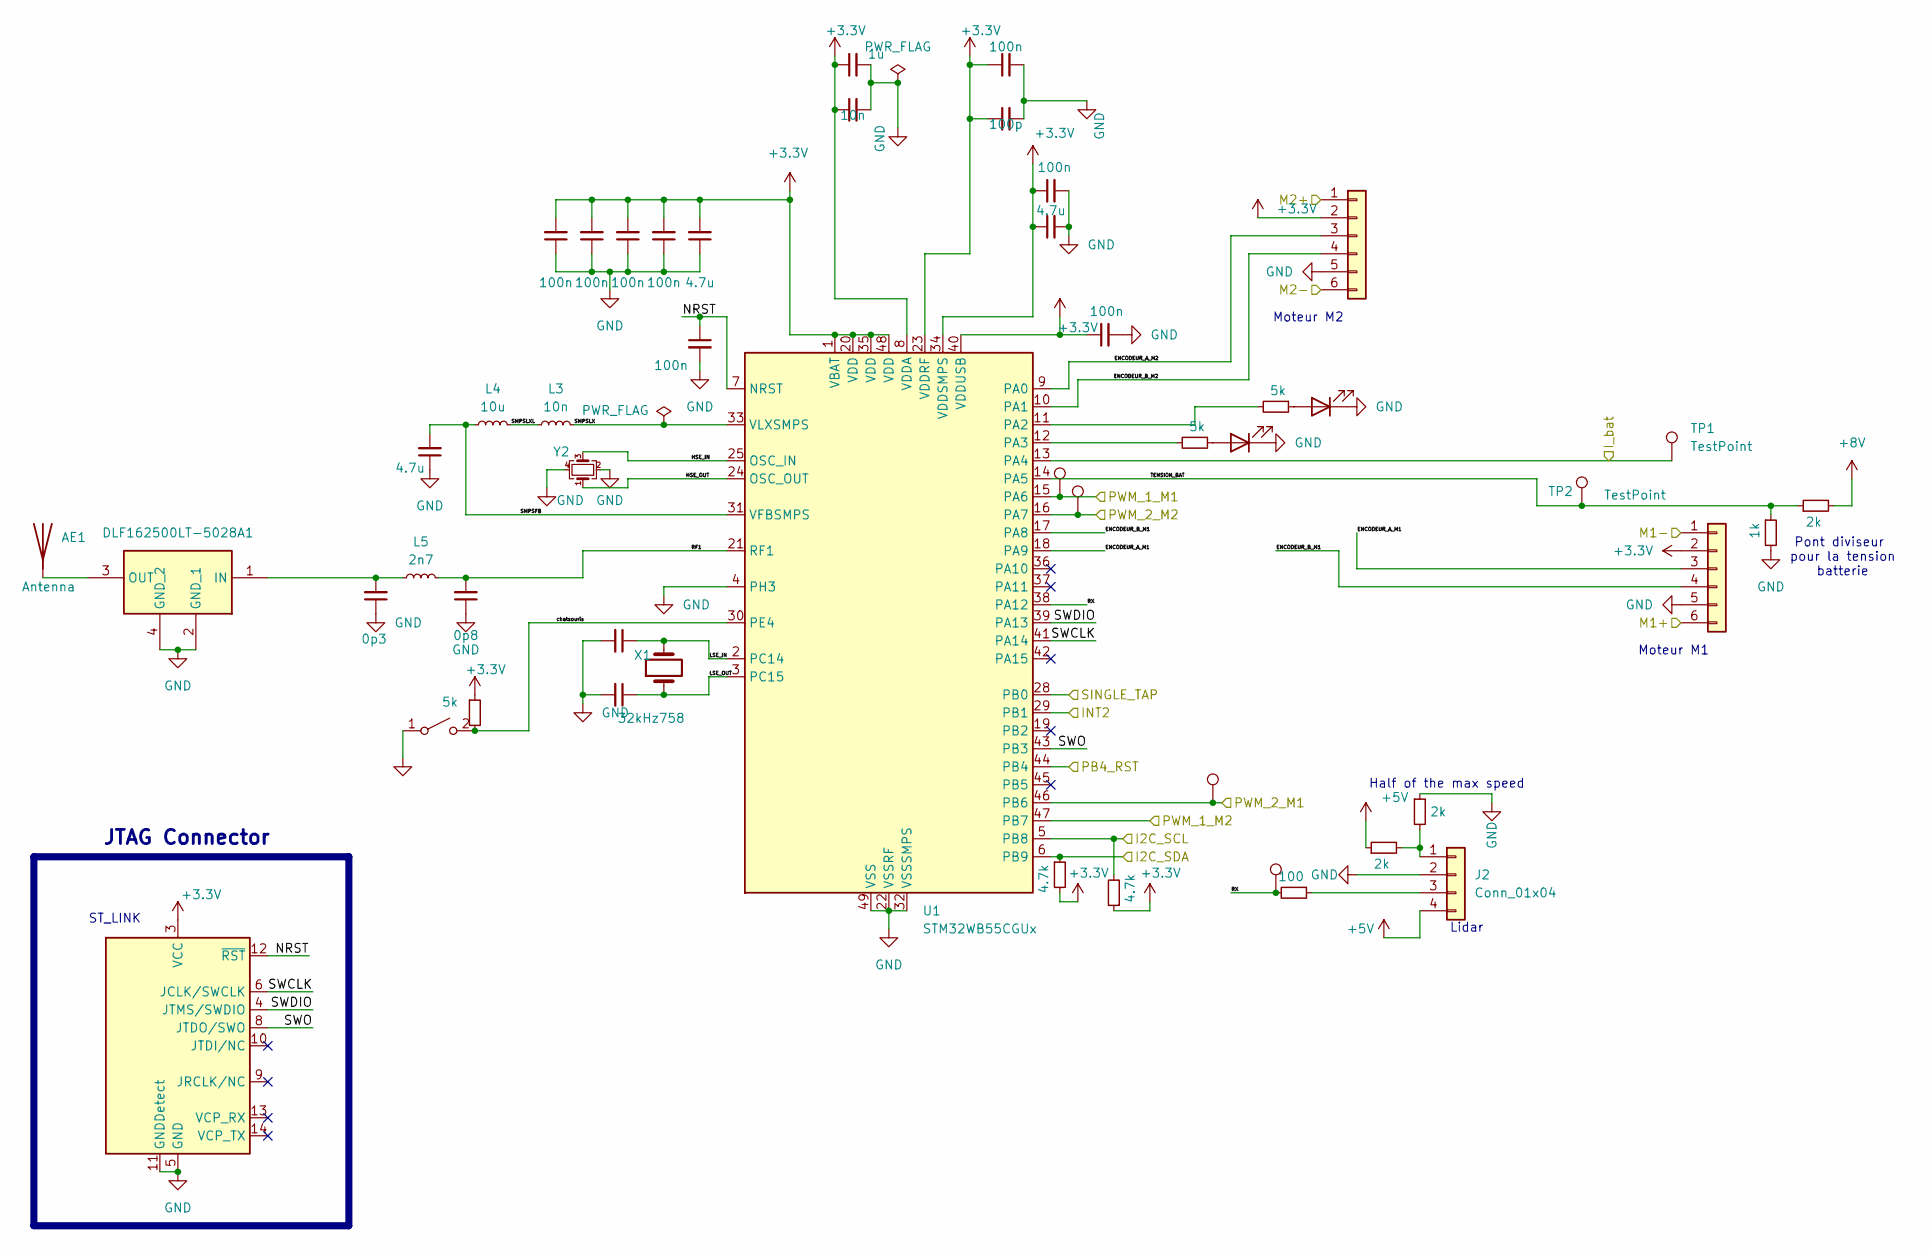
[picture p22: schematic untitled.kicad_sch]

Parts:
AE1: Antenna; 2.4GHz BLE
C1: 10n; C_0402_1005Metric
C2: 1u; C_0402_1005Metric
C5, C6, C7, C8, C9, C11, C38: 100n; C_0603_1608Metric
C10: 100p; C_0603_1608Metric
C12, C39, C43: 4.7u; C_0603_1608Metric
C13, C14: 13p; C_0402_1005Metric
C40: 0p3; C_0402_1005Metric
C41: 0p8; C_0402_1005Metric
C42: 100n; C_0402_1005Metric
D1, D2: LED; LED_0603_1608Metric
FL1: DLF162500LT-5028A1; DLF162500LT5028A1; Mouser Part Number 810-DLF16250LT5028A1
J1: Conn_ST_STDC14; PinHeader_2x07_P1.27mm_Vertical_SMD
J2: Conn_01x04; JST_PH_S4B-PH-K_1x04_P2.00mm_Horizontal
J11, J14: Conn_01x06; JST_PH_S6B-PH-SM4-TB_1x06-1MP_P2.00mm_Horizontal
L3: 10n; L_0402_1005Metric
L4: 10u; L_0805_2012Metric
L5: 2n7; L_0402_1005Metric
R18, R19, R24: 5k; R_0603_1608Metric
R25: 100; R_0603_1608Metric
R26, R27, R33: 2k; R_0603_1608Metric
R28, R29: 4.7k; R_0603_1608Metric
R32: 1k; R_0603_1608Metric
SW2: SW_SPST; SW_SPST_B3U-1000P-B
TP1, TP2, TP4, TP5, TP7, TP9: TestPoint; TestPoint_Pad_D1.5mm
U1: STM32WB55CGUx; QFN-48-1EP_7x7mm_P0.5mm_EP5.6x5.6mm
X1: 32kHz758; ABS06N32768kHzT
Y2: Crystal_GND24_Small; Murata 32MHz

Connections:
+3.3V: C1.1, C2.1, C5.2, C6.2, C7.2, C8.2, C9.1, C10.1, C11.1, C12.1, C38.1, C43.2, J1.3 (VCC), J11.2, J14.2, R24.1, R28.2, R29.1, U1.1 (VBAT), U1.8 (VDDA), U1.20 (VDD), U1.23 (VDDRF), U1.34 (VDDSMPS), U1.35 (VDD), U1.40 (VDDUSB), U1.48 (VDD); also elsewhere on the board
+5V: J2.4, R27.1; also elsewhere on the board
+8V: R33.2; also elsewhere on the board
/I2C_SCL: R29.2, U1.5 (PB8); also elsewhere on the board
/I2C_SDA: R28.1, U1.6 (PB9); also elsewhere on the board
/INT2: U1.29 (PB1); also elsewhere on the board
/I_bat: TP1.1, U1.13 (PA4); also elsewhere on the board
/M1+: J11.6; also elsewhere on the board
/M1-: J11.1; also elsewhere on the board
/M2+: J14.1; also elsewhere on the board
/M2-: J14.6; also elsewhere on the board
/PB4_RST: U1.44 (PB4); also elsewhere on the board
/PWM_1_M1: TP4.1, U1.15 (PA6); also elsewhere on the board
/PWM_1_M2: U1.47 (PB7); also elsewhere on the board
/PWM_2_M1: TP9.1, U1.46 (PB6); also elsewhere on the board
/PWM_2_M2: TP5.1, U1.16 (PA7); also elsewhere on the board
/SINGLE_TAP: U1.28 (PB0); also elsewhere on the board
/STM32/ENCODEUR_A_M1: J11.3, U1.18 (PA9)
/STM32/ENCODEUR_A_M2: J14.3, U1.9 (PA0)
/STM32/ENCODEUR_B_M1: J11.4, U1.17 (PA8)
/STM32/ENCODEUR_B_M2: J14.4, U1.10 (PA1)
/STM32/HSE_IN: U1.25 (OSC_IN), Y2.3
/STM32/HSE_OUT: U1.24 (OSC_OUT), Y2.1
/STM32/LSE_IN: C13.1, U1.2 (PC14), X1.2
/STM32/LSE_OUT: C14.1, U1.3 (PC15), X1.1
/STM32/NRST: C42.1, J1.12 (~RST), U1.7 (NRST)
/STM32/RF1: C41.2, L5.2, U1.21 (RF1)
/STM32/RX: R25.2, TP7.1, U1.38 (PA12)
/STM32/SMPSFB: C39.2, L4.1, U1.31 (VFBSMPS)
/STM32/SMPSLX: L3.2, U1.33 (VLXSMPS)
/STM32/SMPSLXL: L3.1, L4.2
/STM32/SWCLK: J1.6 (JCLK/SWCLK), U1.41 (PA14)
/STM32/SWDIO: J1.4 (JTMS/SWDIO), U1.39 (PA13)
/STM32/SWO: J1.8 (JTDO/SWO), U1.43 (PB3)
/STM32/TENSION_BAT: R32.1, R33.1, TP2.1, U1.14 (PA5)
/STM32/chatsouris: R24.2, SW2.2 (B), U1.30 (PE4)
GND: C1.2, C2.2, C5.1, C6.1, C7.1, C8.1, C9.2, C10.2, C11.2, C12.2, C13.2, C14.2, C38.2, C39.1, C40.1, C41.1, C42.2, C43.1, D1.1 (K), D2.1 (K), FL1.2 (GND_1), FL1.4 (GND_2), J1.5 (GND), J1.7 (GND), J1.11 (GNDDetect), J2.2, J11.5, J14.5, R26.1, R32.2, SW2.1 (A), U1.4 (PH3), U1.22 (VSSRF), U1.32 (VSSSMPS), U1.49 (VSS), Y2.2, Y2.4; also elsewhere on the board
unnamed: AE1.1 (A), FL1.3 (OUT)
unnamed: D1.2 (A), R18.1
unnamed: D2.2 (A), R19.1
unnamed: C40.2, FL1.1 (IN), L5.1
unnamed: J2.1, R26.2, R27.2
unnamed: J2.3, R25.1
unnamed: R18.2, U1.11 (PA2)
unnamed: R19.2, U1.12 (PA3)

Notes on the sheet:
Pont diviseur pour la tension batterie
Moteur M2
Moteur M1
ST_LINK
JTAG Connector
Lidar
Half of the max speed

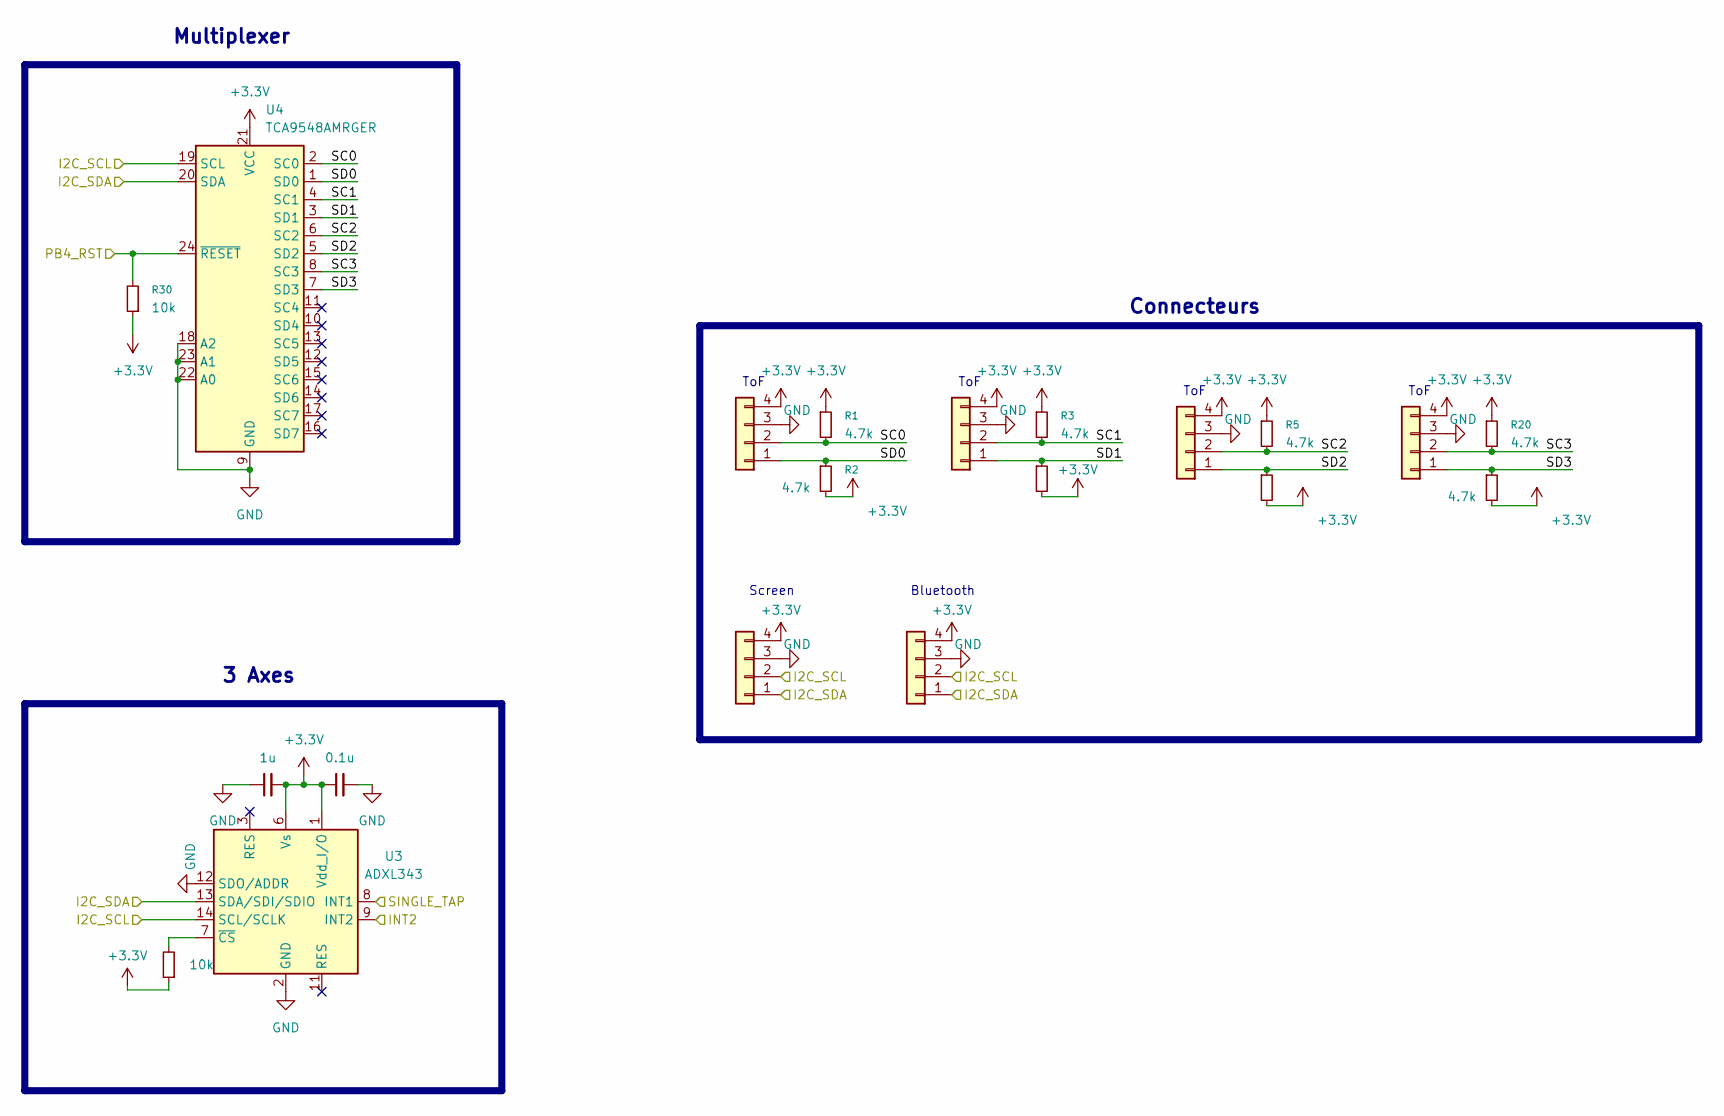
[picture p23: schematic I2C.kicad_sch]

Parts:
C36: 0.1u; C_0603_1608Metric
C37: 1u; C_0603_1608Metric
J3, J4, J5, J6, J7, J8: Conn_01x04; JST_PH_B4B-PH-K_1x04_P2.00mm_Vertical
R1, R2, R3, R4, R5, R6, R20, R21: 4.7k; R_0603_1608Metric
R30, R31: 10k; R_0603_1608Metric
U3: ADXL343; LGA-14_3x5mm_P0.8mm_LayoutBorder1x6y
U4: TCA9548AMRGER; Texas_RGE0024C_VQFN-24-1EP_4x4mm_P0.5mm_EP2.1x2.1mm

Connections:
+3.3V: C36.1, C37.2, J3.4, J4.4, J5.4, J6.4, J7.4, J8.4, R1.1, R2.2, R3.1, R4.2, R5.1, R6.2, R20.1, R21.2, R30.1, R31.1, U3.1 (Vdd_I/O), U3.6 (Vs), U4.21 (VCC); also elsewhere on the board
/I2C/SC0: J3.2, R1.2, U4.2 (SC0)
/I2C/SC1: J4.2, R3.2, U4.4 (SC1)
/I2C/SC2: J5.2, R5.2, U4.6 (SC2)
/I2C/SC3: J6.2, R20.2, U4.8 (SC3)
/I2C/SD0: J3.1, R2.1, U4.1 (SD0)
/I2C/SD1: J4.1, R4.1, U4.3 (SD1)
/I2C/SD2: J5.1, R6.1, U4.5 (SD2)
/I2C/SD3: J6.1, R21.1, U4.7 (SD3)
/I2C_SCL: J7.2, J8.2, U3.14 (SCL/SCLK), U4.19 (SCL); also elsewhere on the board
/I2C_SDA: J7.1, J8.1, U3.13 (SDA/SDI/SDIO), U4.20 (SDA); also elsewhere on the board
/INT2: U3.9 (INT2); also elsewhere on the board
/PB4_RST: R30.2, U4.24 (~RESET); also elsewhere on the board
/SINGLE_TAP: U3.8 (INT1); also elsewhere on the board
GND: C36.2, C37.1, J3.3, J4.3, J5.3, J6.3, J7.3, J8.3, U3.2 (GND), U3.4 (GND), U3.5 (GND), U3.12 (SDO/ADDR), U4.9 (GND), U4.18 (A2), U4.22 (A0), U4.23 (A1); also elsewhere on the board
unnamed: R31.2, U3.7 (~CS)

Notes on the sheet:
Screen
ToF
3 Axes
Bluetooth
Multiplexer
Connecteurs

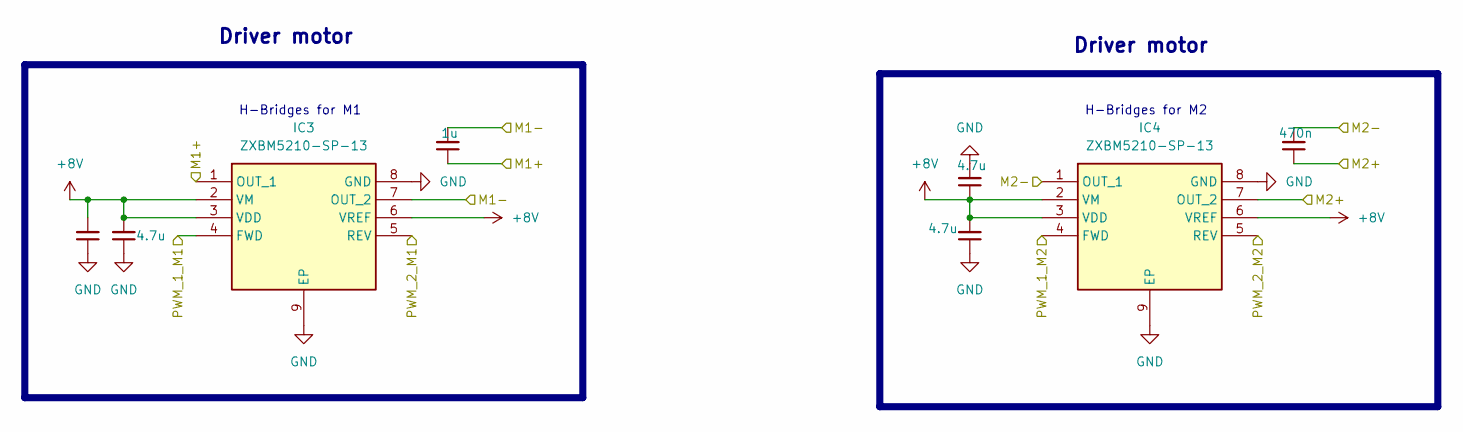
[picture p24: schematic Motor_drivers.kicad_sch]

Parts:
C29, C30, C32, C33: 4.7u; C_0603_1608Metric
C31: 1u; C_0603_1608Metric
C34: 470n; C_0603_1608Metric
IC3, IC4: ZXBM5210-SP-13; Diodes_SO-8EP; Mouser Part Number 621-ZXBM5210-SP-13

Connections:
+8V: C29.2, C30.2, C32.1, C33.2, IC3.2 (VM), IC3.3 (VDD), IC3.6 (VREF), IC4.2 (VM), IC4.3 (VDD), IC4.6 (VREF); also elsewhere on the board
/M1+: C31.1, IC3.1 (OUT_1); also elsewhere on the board
/M1-: C31.2, IC3.7 (OUT_2); also elsewhere on the board
/M2+: C34.1, IC4.7 (OUT_2); also elsewhere on the board
/M2-: C34.2, IC4.1 (OUT_1); also elsewhere on the board
/PWM_1_M1: IC3.4 (FWD); also elsewhere on the board
/PWM_1_M2: IC4.4 (FWD); also elsewhere on the board
/PWM_2_M1: IC3.5 (REV); also elsewhere on the board
/PWM_2_M2: IC4.5 (REV); also elsewhere on the board
GND: C29.1, C30.1, C32.2, C33.1, IC3.8 (GND), IC3.9 (EP), IC4.8 (GND), IC4.9 (EP); also elsewhere on the board

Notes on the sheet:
Driver motor
H-Bridges for M1
H-Bridges for M2

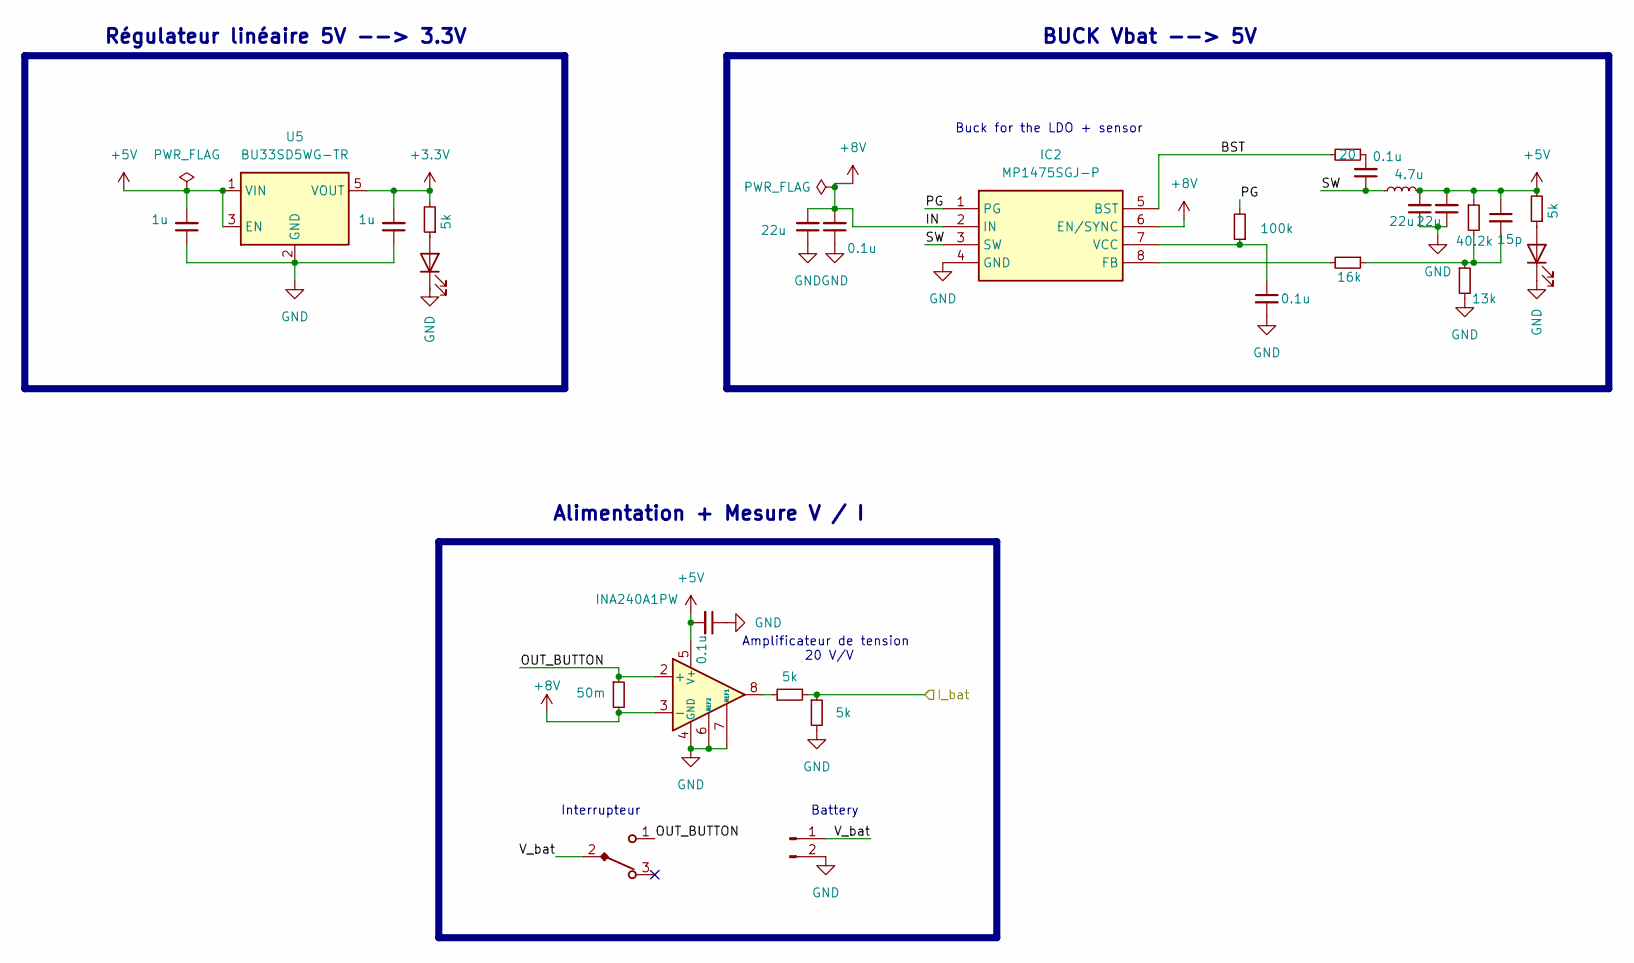
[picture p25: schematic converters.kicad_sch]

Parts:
C15, C16: 1u; C_0603_1608Metric
C21, C23, C27: 22u; C_0603_1608Metric
C22, C24, C25, C35: 0.1u; C_0603_1608Metric
C28: 15p; C_0603_1608Metric
D3, D4: LED; LED_0603_1608Metric
IC2: MP1475SGJ-P; TSOT 23-8; Mouser Part Number 946-MP1475SGJ-P
J9: Conn_01x02_Pin; JST_XH_B2B-XH-A_1x02_P2.50mm_Vertical
L2: 4.7u; 74404054068
R8: 20; R_0603_1608Metric
R9: 16k; R_0603_1608Metric
R10: 40.2k; R_0603_1608Metric
R11: 13k; R_0603_1608Metric
R12: 100k; R_0603_1608Metric
R15: 50m; R_6431
R16, R17, R22, R23: 5k; R_0603_1608Metric
SW1: SW_Wurth; SW_Wurth_WS-TOTV_472121020311; Part Number 472121010111
U2: INA240A1PW; TSSOP-8_4.4x3mm_P0.65mm
U5: BU33SD5WG-TR; SSOP-5

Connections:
+3.3V: C16.2, R22.2, U5.5 (VOUT); also elsewhere on the board
+5V: C15.2, C23.2, C27.2, C28.1, C35.2, L2.2, R10.1, R23.2, U2.5 (V+), U5.1 (VIN), U5.3 (EN); also elsewhere on the board
+8V: C21.2, C25.2, IC2.2 (IN), IC2.6 (EN/SYNC), R15.2, U2.3 (-); also elsewhere on the board
/Converters/BST: IC2.5 (BST), R8.2
/Converters/OUT_BUTTON: R15.1, SW1.1, U2.2 (+)
/Converters/PG: IC2.1 (PG), R12.2
/Converters/SW: C22.1, IC2.3 (SW), L2.1
/Converters/V_bat: J9.1, SW1.2
/I_bat: R16.1, R17.2; also elsewhere on the board
GND: C15.1, C16.1, C21.1, C23.1, C24.2, C25.1, C27.1, C35.1, D3.1 (K), D4.1 (K), IC2.4 (GND), J9.2, R11.2, R16.2, U2.1 (GND), U2.4 (GND), U2.6 (REF2), U2.7 (REF1), U5.2 (GND); also elsewhere on the board
unnamed: C22.2, R8.1
unnamed: C28.2, R9.1, R10.2, R11.1
unnamed: D3.2 (A), R22.1
unnamed: D4.2 (A), R23.1
unnamed: IC2.8 (FB), R9.2
unnamed: C24.1, IC2.7 (VCC), R12.1
unnamed: R17.1, U2.8

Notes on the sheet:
Battery
Buck for the LDO + sensor
BUCK Vbat --> 5V
Interrupteur
Alimentation + Mesure V / I
Amplificateur de tension 20 V/V
Régulateur linéaire 5V --> 3.3V

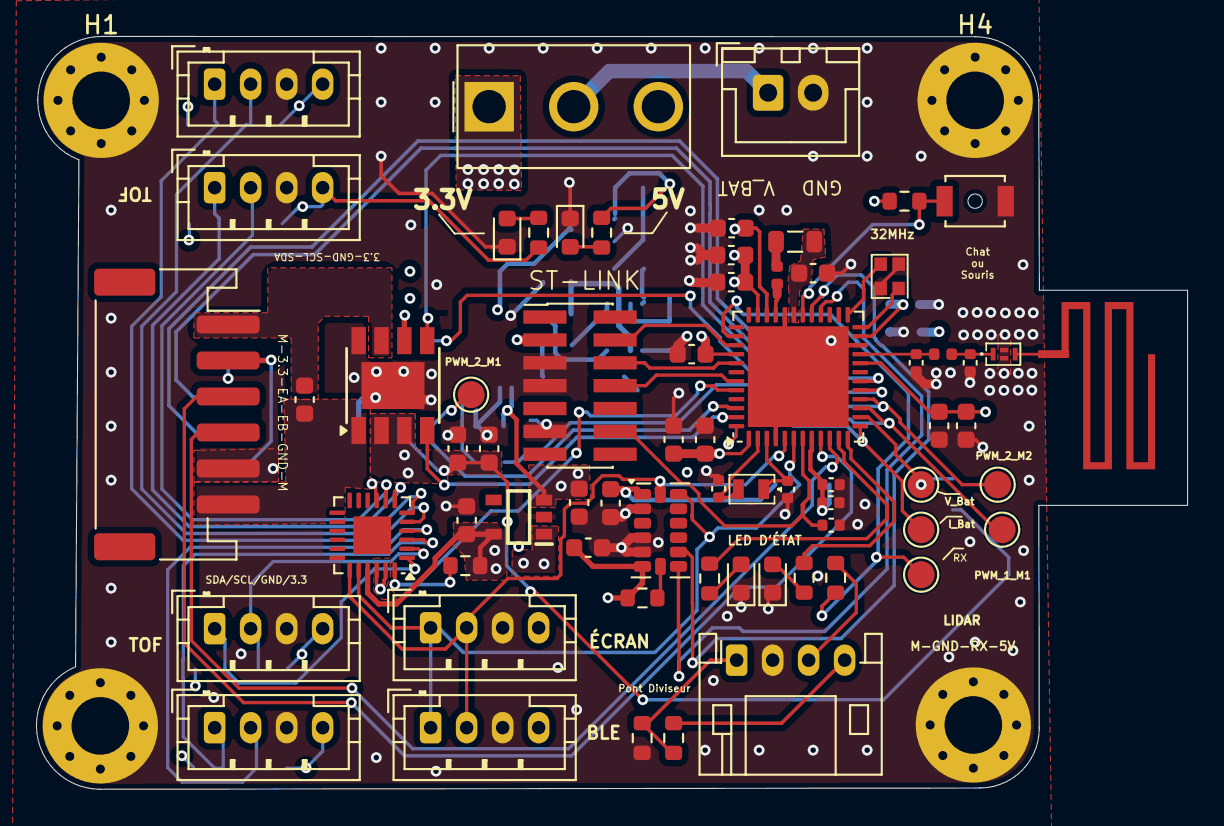
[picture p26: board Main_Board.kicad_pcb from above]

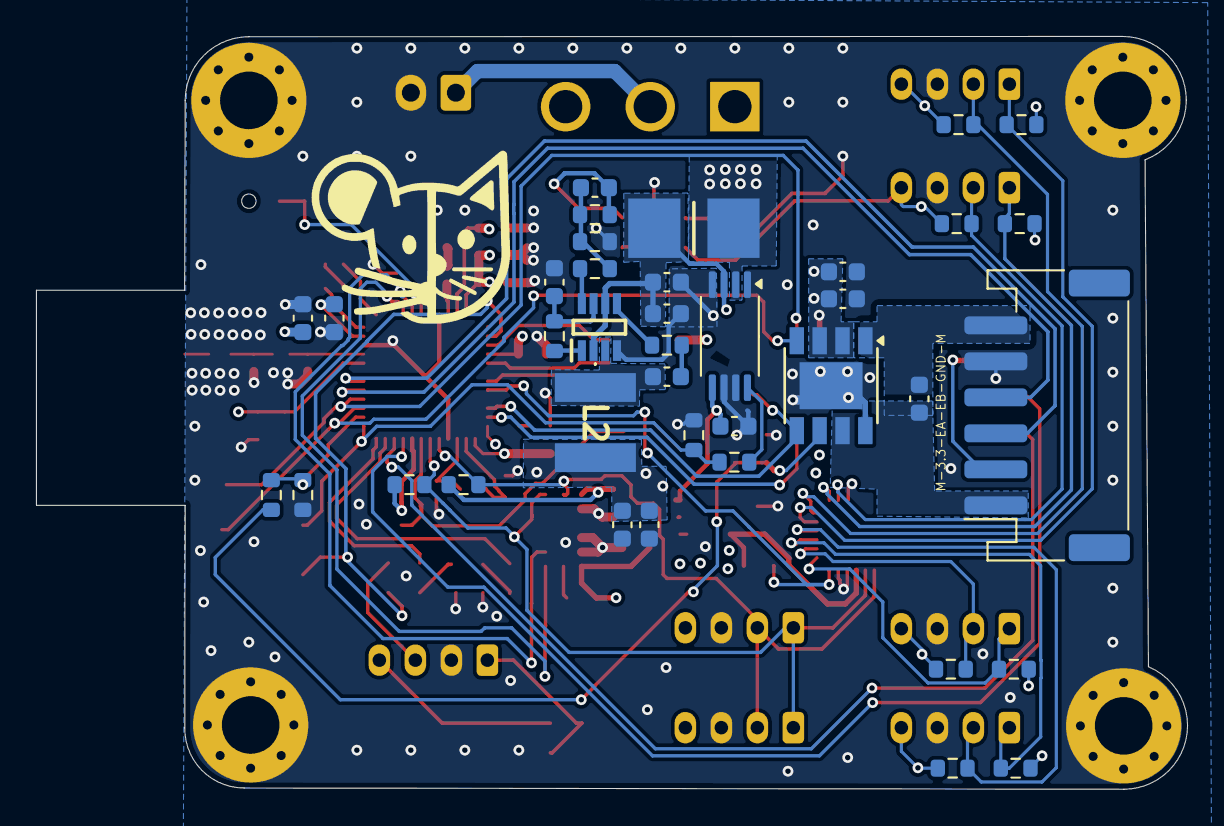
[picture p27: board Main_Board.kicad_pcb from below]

Board: 4 copper layers, 64.0 x 41.8 mm, 109 parts (38 on the bottom side), 66 nets.

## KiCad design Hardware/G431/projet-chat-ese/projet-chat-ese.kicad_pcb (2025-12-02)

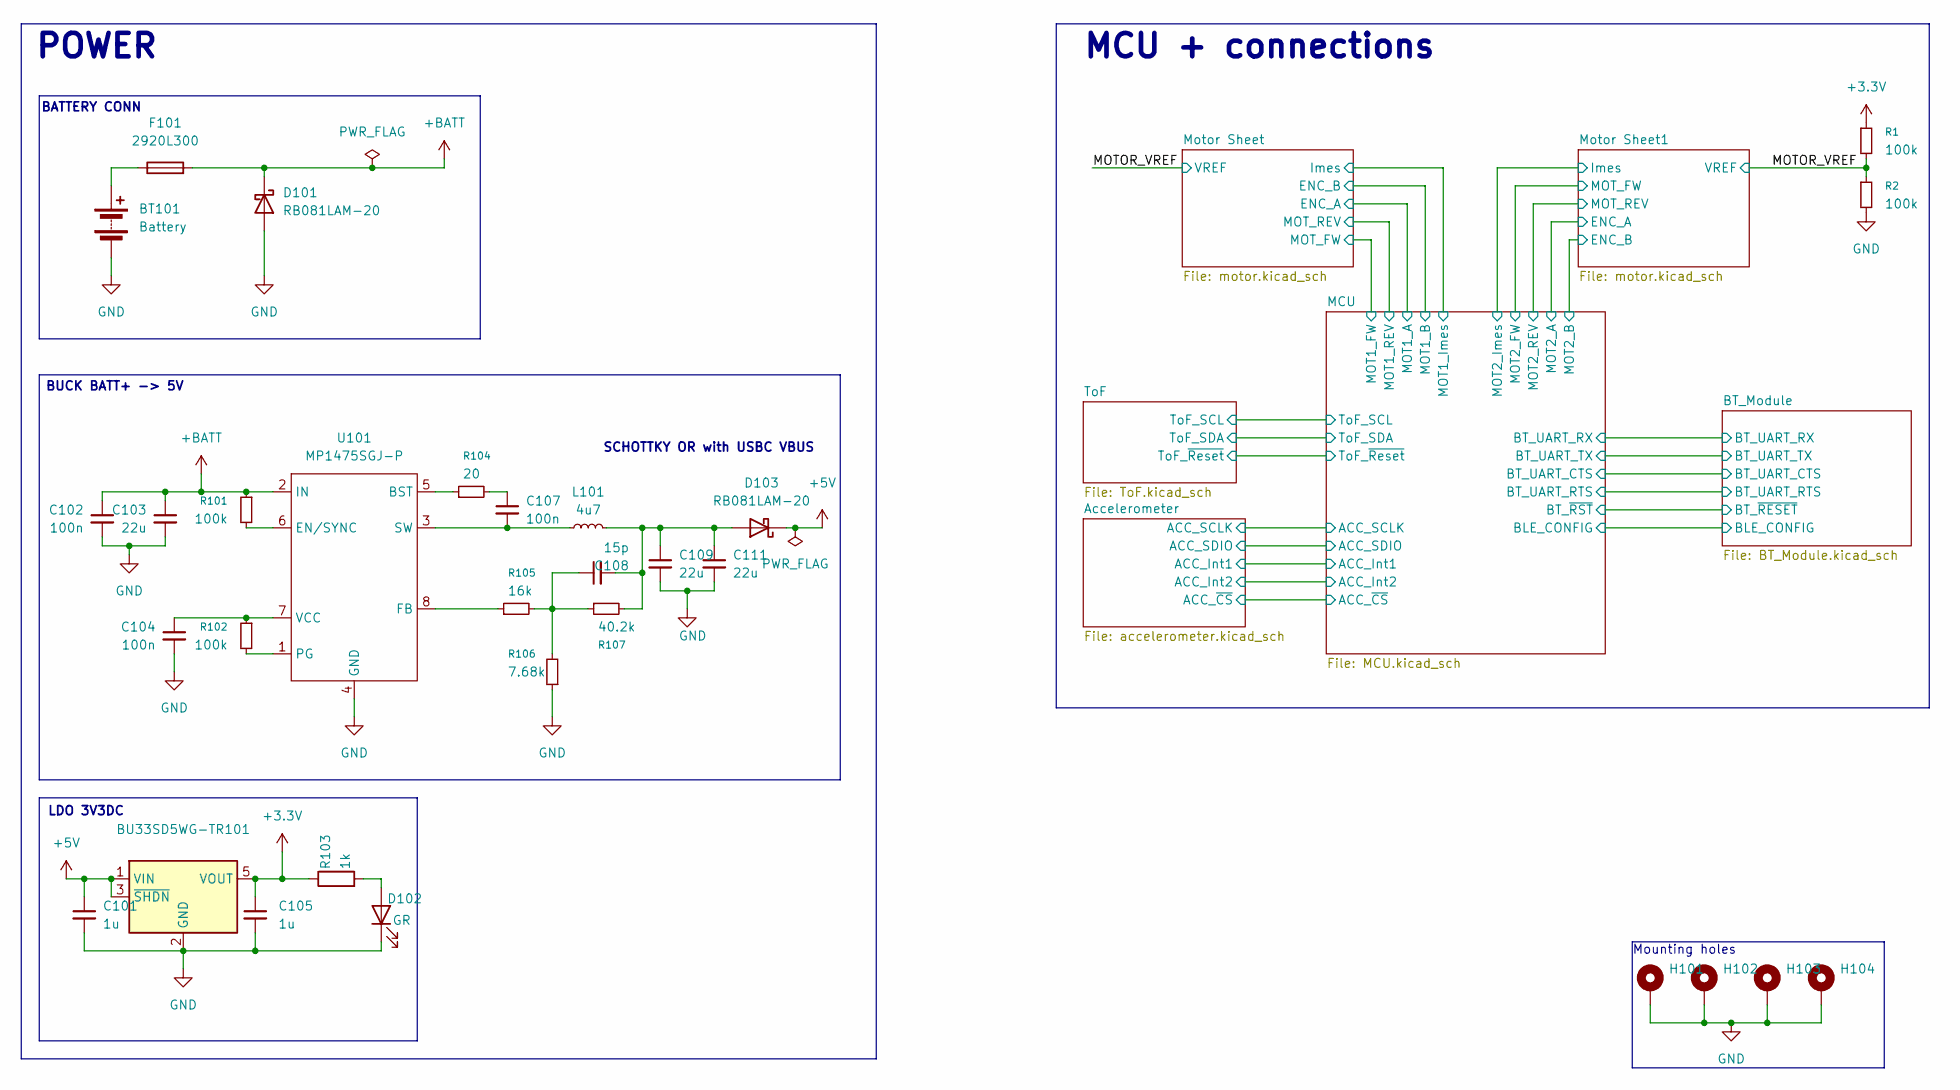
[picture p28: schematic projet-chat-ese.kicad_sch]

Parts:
BT101: Battery; JST_XH_B2B-XH-AM_1x02_P2.50mm_Vertical
BU33SD5WG-TR101: LM1117DT-3.3; SOT-23-5
C101, C105: 1u; C_0603_1608Metric_Pad1.08x0.95mm_HandSolder
C102, C104, C107: 100n; C_0402_1005Metric
C103, C109, C111: 22u; C_0805_2012Metric
C108: 15p; C_0402_1005Metric
D101, D103: RB081LAM-20; D_SOD-128
D102: GR; LED_0603_1608Metric
F101: 2920L300
H101, H102, H103, H104: MountingHole_Pad; MountingHole_3.2mm_M3_DIN965_Pad_TopBottom
L101: 4u7; L_APV_ANR5020
R1, R2, R101, R102: 100k; R_0402_1005Metric
R103: 1k; R_0402_1005Metric
R104: 20; R_0402_1005Metric
R105: 16k; R_0402_1005Metric
R106: 7.68k; R_0402_1005Metric
R107: 40.2k; R_0402_1005Metric
U101: MP1475SGJ-P; TSOT-23-8; MPN MP1475SGJ-P

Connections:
+3.3V: BU33SD5WG-TR101.5 (VOUT), C105.1, R1.1, R103.1; also elsewhere on the board
+5V: BU33SD5WG-TR101.1 (VIN), BU33SD5WG-TR101.3 (~SHDN), C101.1, D103.1 (K); also elsewhere on the board
+BATT: C102.1, C103.1, D101.1 (K), F101.2, R101.1, U101.2 (IN); also elsewhere on the board
/MOTOR_VREF: R1.2, R2.1; also elsewhere on the board
GND: BT101.1 (-), BU33SD5WG-TR101.2 (GND), C101.2, C102.2, C103.2, C104.2, C105.2, C109.2, C111.2, D101.2 (A), D102.1 (K), H101.1, H102.1, H103.1, H104.1, R2.2, R106.1, U101.4 (GND); also elsewhere on the board
unnamed: BT101.2 (+), F101.1
unnamed: C107.1, R104.2
unnamed: C108.1, R105.2, R106.2, R107.1
unnamed: D102.2 (A), R103.2
unnamed: C108.2, C109.1, C111.1, D103.2 (A), L101.1, R107.2
unnamed: R104.1, U101.5 (BST)
unnamed: R101.2, U101.6 (EN/SYNC)
unnamed: R105.1, U101.8 (FB)
unnamed: R102.2, U101.1 (PG)
unnamed: C107.2, L101.2, U101.3 (SW)
unnamed: C104.1, R102.1, U101.7 (VCC)

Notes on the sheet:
Mounting holes
LDO 3V3DC
MCU + connections
BATTERY CONN
SCHOTTKY OR with USBC VBUS
POWER
BUCK BATT+ -> 5V

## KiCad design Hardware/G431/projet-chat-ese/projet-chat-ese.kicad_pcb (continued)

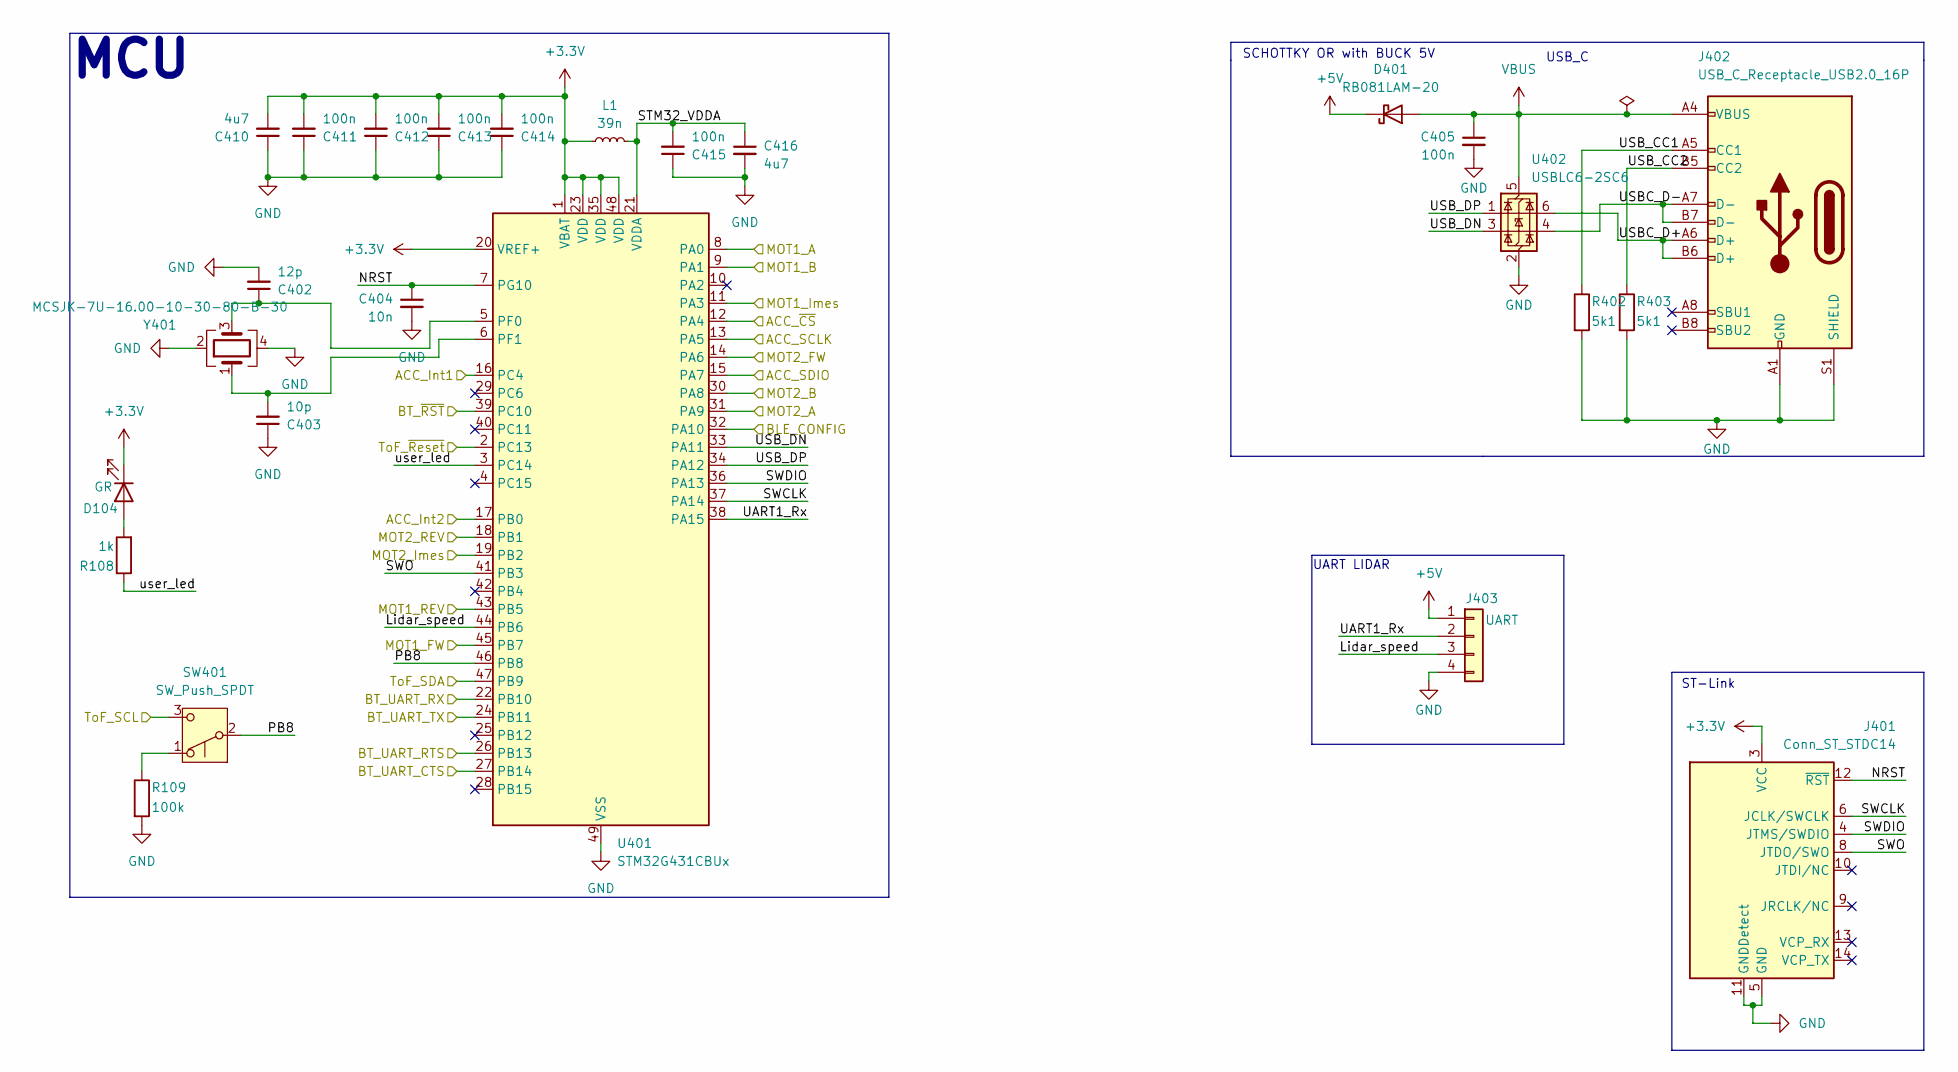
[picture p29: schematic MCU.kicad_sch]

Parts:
C402: 12p; C_0402_1005Metric
C403: 10p; C_0402_1005Metric
C404: 10n; C_0402_1005Metric
C405, C411, C412, C413, C414, C415: 100n; C_0402_1005Metric
C410, C416: 4u7; C_0402_1005Metric
D104: GR; LED_0603_1608Metric
D401: RB081LAM-20; D_SOD-128
J401: Conn_ST_STDC14; PinHeader_2x07_P1.27mm_Vertical_SMD
J402: USB_C_Receptacle_USB2.0_16P; USB_C_Receptacle_XKB_U262-16XN-4BVC11
J403: UART; JST_PH_B4B-PH-K_1x04_P2.00mm_Vertical
L1: 39n; L_0603_1608Metric
R108: 1k; R_0402_1005Metric
R109: 100k; R_0402_1005Metric
R402, R403: 5k1; R_0402_1005Metric
SW401: SW_Push_SPDT
U401: STM32G431CBUx; QFN-48-1EP_7x7mm_P0.5mm_EP5.6x5.6mm
U402: USBLC6-2SC6; SOT-23-6
Y401: MCSJK-7U-16.00-10-30-80-B-30; SMD 3225

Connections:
+3.3V: C410.2, C411.2, C412.2, C413.2, C414.2, D104.1 (K), J401.3 (VCC), L1.1, U401.1 (VBAT), U401.20 (VREF+), U401.23 (VDD), U401.35 (VDD), U401.48 (VDD); also elsewhere on the board
+5V: D401.1 (K), J403.1; also elsewhere on the board
/Accelerometer/ACC_Int1: U401.16 (PC4); also elsewhere on the board
/Accelerometer/ACC_Int2: U401.17 (PB0); also elsewhere on the board
/Accelerometer/ACC_SCLK: U401.13 (PA5); also elsewhere on the board
/Accelerometer/ACC_SDIO: U401.15 (PA7); also elsewhere on the board
/Accelerometer/ACC_~CS: U401.12 (PA4); also elsewhere on the board
/BT_Module/BLE_CONFIG: U401.32 (PA10); also elsewhere on the board
/BT_Module/BT_UART_CTS: U401.27 (PB14); also elsewhere on the board
/BT_Module/BT_UART_RTS: U401.26 (PB13); also elsewhere on the board
/BT_Module/BT_UART_RX: U401.22 (PB10); also elsewhere on the board
/BT_Module/BT_UART_TX: U401.24 (PB11); also elsewhere on the board
/BT_Module/BT_~RESET: U401.39 (PC10); also elsewhere on the board
/MCU/Lidar_speed: J403.3, U401.44 (PB6)
/MCU/MOT1_A: U401.8 (PA0); also elsewhere on the board
/MCU/MOT1_B: U401.9 (PA1); also elsewhere on the board
/MCU/MOT1_FW: U401.45 (PB7); also elsewhere on the board
/MCU/MOT1_Imes: U401.11 (PA3); also elsewhere on the board
/MCU/MOT1_REV: U401.43 (PB5); also elsewhere on the board
/MCU/MOT2_A: U401.31 (PA9); also elsewhere on the board
/MCU/MOT2_B: U401.30 (PA8); also elsewhere on the board
/MCU/MOT2_FW: U401.14 (PA6); also elsewhere on the board
/MCU/MOT2_Imes: U401.19 (PB2); also elsewhere on the board
/MCU/MOT2_REV: U401.18 (PB1); also elsewhere on the board
/MCU/NRST: C404.1, J401.12 (~RST), U401.7 (PG10)
/MCU/STM32_VDDA: C415.2, C416.1, L1.2, U401.21 (VDDA)
/MCU/SWCLK: J401.6 (JCLK/SWCLK), U401.37 (PA14)
/MCU/SWDIO: J401.4 (JTMS/SWDIO), U401.36 (PA13)
/MCU/SWO: J401.8 (JTDO/SWO), U401.41 (PB3)
/MCU/ToF_SCL: SW401.2 (B), U401.46 (PB8); also elsewhere on the board
/MCU/ToF_SDA: U401.47 (PB9); also elsewhere on the board
/MCU/ToF_~Reset: U401.2 (PC13); also elsewhere on the board
/MCU/UART1_Rx: J403.2, U401.38 (PA15)
/MCU/USBC_D+: J402.A6 (D+), J402.B6 (D+), U402.6 (I/O1)
/MCU/USBC_D-: J402.A7 (D-), J402.B7 (D-), U402.4 (I/O2)
/MCU/USB_CC1: J402.A5 (CC1), R402.1
/MCU/USB_CC2: J402.B5 (CC2), R403.1
/MCU/USB_DN: U401.33 (PA11), U402.3 (I/O2)
/MCU/USB_DP: U401.34 (PA12), U402.1 (I/O1)
GND: C402.2, C403.1, C404.2, C405.2, C410.1, C411.1, C412.1, C413.1, C414.1, C415.1, C416.2, J401.5 (GND), J401.7 (GND), J401.11 (GNDDetect), J402.A1 (GND), J402.A12 (GND), J402.B1 (GND), J402.B12 (GND), J402.S1 (SHIELD), J403.4, R109.2, R402.2, R403.2, U401.49 (VSS), U402.2 (GND), Y401.2, Y401.4; also elsewhere on the board
unnamed: D104.2 (A), R108.2
unnamed: R108.1, U401.3 (PC14)
unnamed: R109.1, SW401.1 (A)
unnamed: C402.1, U401.5 (PF0), Y401.3
unnamed: C403.2, U401.6 (PF1), Y401.1
VBUS: C405.1, D401.2 (A), J402.A4 (VBUS), J402.A9 (VBUS), J402.B4 (VBUS), J402.B9 (VBUS), U402.5 (VBUS)

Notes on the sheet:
ST-Link
USB_C
SCHOTTKY OR with BUCK 5V
MCU
UART LIDAR

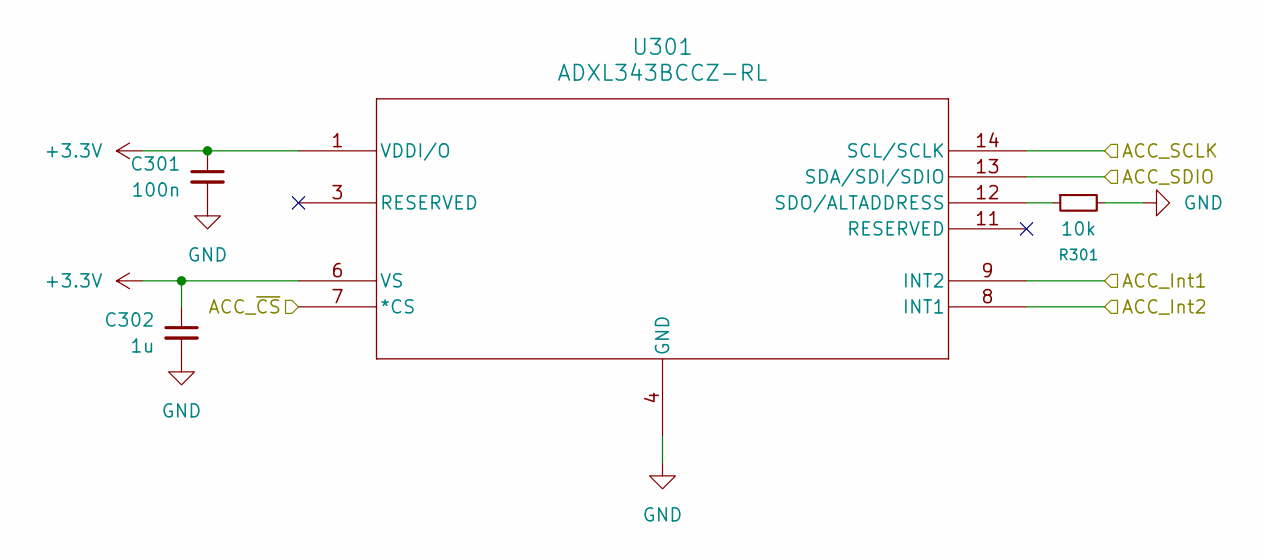
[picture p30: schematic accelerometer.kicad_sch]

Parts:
C301: 100n; C_0402_1005Metric
C302: 1u; C_0603_1608Metric
R301: 10k; R_0402_1005Metric
U301: ADXL343BCCZ-RL; LGA_CC-14-1_ADI

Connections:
+3.3V: C301.1, C302.1, U301.1 (VDDI/O), U301.6 (VS); also elsewhere on the board
/Accelerometer/ACC_Int1: U301.9 (INT2); also elsewhere on the board
/Accelerometer/ACC_Int2: U301.8 (INT1); also elsewhere on the board
/Accelerometer/ACC_SCLK: U301.14 (SCL/SCLK); also elsewhere on the board
/Accelerometer/ACC_SDIO: U301.13 (SDA/SDI/SDIO); also elsewhere on the board
/Accelerometer/ACC_~CS: U301.7 (*CS); also elsewhere on the board
GND: C301.2, C302.2, R301.2, U301.2 (GND), U301.4 (GND), U301.5 (GND); also elsewhere on the board
unnamed: R301.1, U301.12 (SDO/ALTADDRESS)

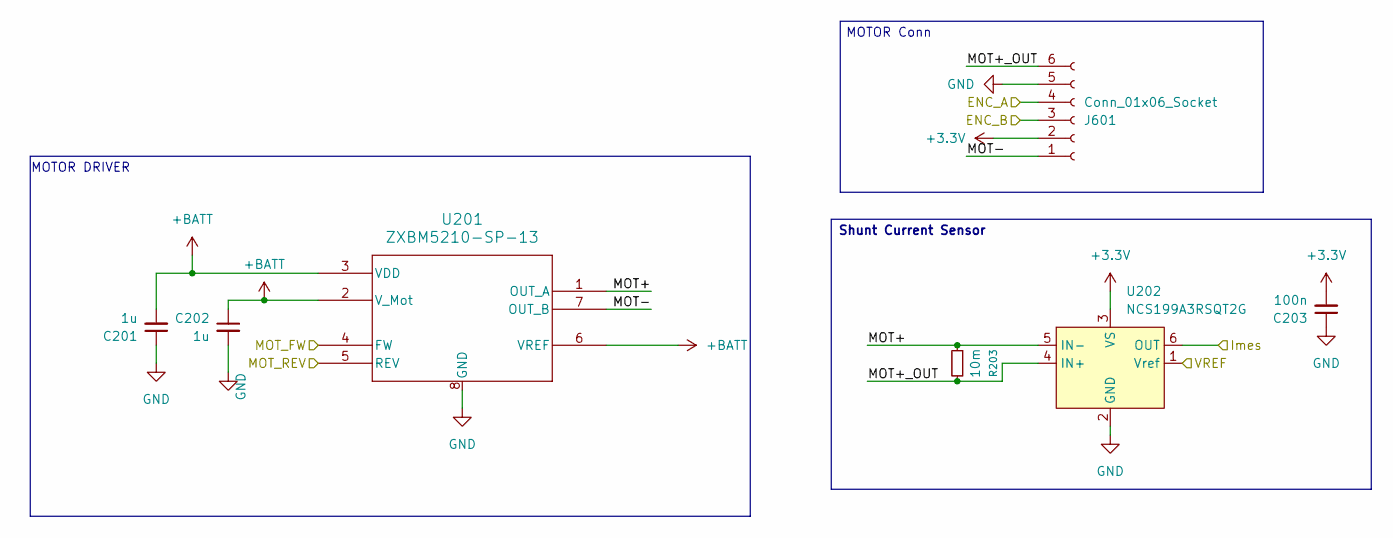
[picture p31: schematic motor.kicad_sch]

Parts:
C201, C202: 1u; C_0603_1608Metric
C203: 100n; C_0402_1005Metric
J601: Conn_01x06_Socket; JST_PH_B6B-PH-K_1x06_P2.00mm_Vertical
R203: 10m; R_0805_2012Metric; MPN 580 060 720 008
U201: ZXBM5210-SP-13; SOIC-8-1EP_3.9x4.9mm_P1.27mm_EP2.29x3mm
U202: NCS199A3RSQT2G; SC70-6

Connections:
+3.3V: C203.2, J601.2, U202.3 (VS); also elsewhere on the board
+BATT: C201.2, C202.1, U201.2 (V_Mot), U201.3 (VDD), U201.6 (VREF); also elsewhere on the board
/MCU/MOT1_A: J601.4; also elsewhere on the board
/MCU/MOT1_B: J601.3; also elsewhere on the board
/MCU/MOT1_FW: U201.4 (FW); also elsewhere on the board
/MCU/MOT1_Imes: U202.6 (OUT); also elsewhere on the board
/MCU/MOT1_REV: U201.5 (REV); also elsewhere on the board
/MOTOR_VREF: U202.1 (Vref); also elsewhere on the board
/Motor Sheet/MOT+: R203.1, U201.1 (OUT_A), U202.5 (IN-)
/Motor Sheet/MOT+_OUT: J601.6, R203.2, U202.4 (IN+)
/Motor Sheet/MOT-: J601.1, U201.7 (OUT_B)
GND: C201.1, C202.2, C203.1, J601.5, U201.8 (GND), U201.9 (GND), U202.2 (GND); also elsewhere on the board

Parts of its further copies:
C204: 100n; C_0402_1005Metric
C601, C602: 1u; C_0603_1608Metric
J602: Conn_01x06_Socket; JST_PH_B6B-PH-K_1x06_P2.00mm_Vertical
R204: 10m; R_0805_2012Metric; MPN 580 060 720 008
U601: ZXBM5210-SP-13; SOIC-8-1EP_3.9x4.9mm_P1.27mm_EP2.29x3mm
U602: NCS199A3RSQT2G; SC70-6

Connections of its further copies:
+3.3V: C204.2, J602.2, U602.3 (VS); also elsewhere on the board
+BATT: C601.2, C602.1, U601.2 (V_Mot), U601.3 (VDD), U601.6 (VREF); also elsewhere on the board
/MCU/MOT2_A: J602.4; also elsewhere on the board
/MCU/MOT2_B: J602.3; also elsewhere on the board
/MCU/MOT2_FW: U601.4 (FW); also elsewhere on the board
/MCU/MOT2_Imes: U602.6 (OUT); also elsewhere on the board
/MCU/MOT2_REV: U601.5 (REV); also elsewhere on the board
/MOTOR_VREF: U602.1 (Vref); also elsewhere on the board
/Motor Sheet1/MOT+: R204.1, U601.1 (OUT_A), U602.5 (IN-)
/Motor Sheet1/MOT+_OUT: J602.6, R204.2, U602.4 (IN+)
/Motor Sheet1/MOT-: J602.1, U601.7 (OUT_B)
GND: C204.1, C601.1, C602.2, J602.5, U601.8 (GND), U601.9 (GND), U602.2 (GND); also elsewhere on the board

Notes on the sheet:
MOTOR DRIVER
Shunt Current Sensor
MOTOR Conn

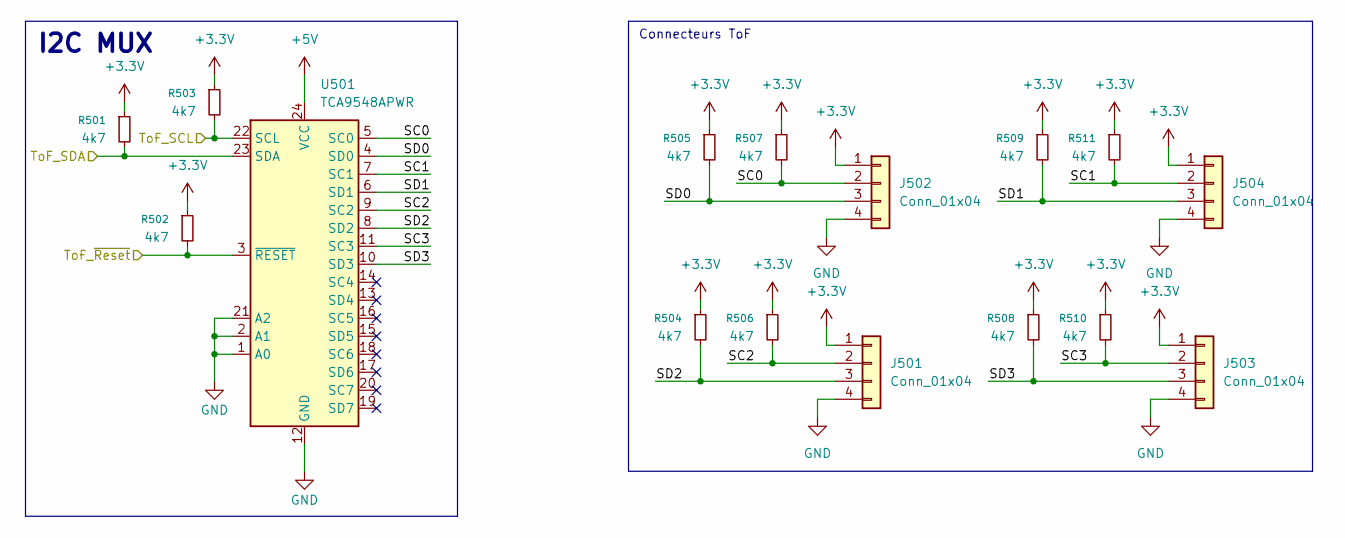
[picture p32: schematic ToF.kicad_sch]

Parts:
J501, J502, J503, J504: Conn_01x04; JST_PH_B4B-PH-K_1x04_P2.00mm_Vertical
R501, R502, R503, R504, R505, R506, R507, R508, R509, R510, R511: 4k7; R_0402_1005Metric
U501: TCA9548APWR; VQFN-24-1EP_4x4mm_P0.5mm_EP2.45x2.45mm

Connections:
+3.3V: J501.1, J502.1, J503.1, J504.1, R501.1, R502.1, R503.1, R504.1, R505.1, R506.1, R507.1, R508.1, R509.1, R510.1, R511.1; also elsewhere on the board
+5V: U501.24 (VCC); also elsewhere on the board
/MCU/ToF_SCL: R503.2, U501.22 (SCL); also elsewhere on the board
/MCU/ToF_SDA: R501.2, U501.23 (SDA); also elsewhere on the board
/MCU/ToF_~Reset: R502.2, U501.3 (~RESET); also elsewhere on the board
/ToF/SC0: J502.2, R507.2, U501.5 (SC0)
/ToF/SC1: J504.2, R511.2, U501.7 (SC1)
/ToF/SC2: J501.2, R506.2, U501.9 (SC2)
/ToF/SC3: J503.2, R510.2, U501.11 (SC3)
/ToF/SD0: J502.3, R505.2, U501.4 (SD0)
/ToF/SD1: J504.3, R509.2, U501.6 (SD1)
/ToF/SD2: J501.3, R504.2, U501.8 (SD2)
/ToF/SD3: J503.3, R508.2, U501.10 (SD3)
GND: J501.4, J502.4, J503.4, J504.4, U501.1 (A0), U501.2 (A1), U501.12 (GND), U501.21 (A2), U501.25 (PAD); also elsewhere on the board

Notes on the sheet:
I2C MUX
Connecteurs ToF


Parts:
C701: 10u; C_0805_2012Metric
D701: LED; LED_0603_1608Metric
R3: 100k; R_0402_1005Metric
R701: 330; R_0402_1005Metric
U701: BM71BLES1FC2-0B04AA; BM71BLES1FC2_MCH

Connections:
+3.3V: C701.1, R3.1, R701.1, U701.14 (VBAT); also elsewhere on the board
/BT_Module/BLE_CONFIG: R3.2, U701.16 (P2_0); also elsewhere on the board
/BT_Module/BT_UART_CTS: U701.11 (P0_0); also elsewhere on the board
/BT_Module/BT_UART_RTS: U701.9 (P3_6); also elsewhere on the board
/BT_Module/BT_UART_RX: U701.7 (HCI_RXD); also elsewhere on the board
/BT_Module/BT_UART_TX: U701.8 (HCI_TXD); also elsewhere on the board
/BT_Module/BT_~RESET: U701.10 (RST_N); also elsewhere on the board
GND: C701.2, U701.2 (GND), U701.13 (GND); also elsewhere on the board
unnamed: D701.2 (A), R701.2
unnamed: D701.1 (K), U701.12 (P0_2)



Board: 4 copper layers, 58.5 x 45.0 mm, 90 parts (33 on the bottom side), 73 nets.

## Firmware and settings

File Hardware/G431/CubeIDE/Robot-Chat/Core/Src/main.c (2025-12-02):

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
/* Includes ------------------------------------------------------------------*/
#include "main.h"
#include "cmsis_os.h"
#include "adc.h"
#include "dma.h"
#include "i2c.h"
#include "spi.h"
#include "tim.h"
#include "usart.h"
#include "usb_device.h"
#include "gpio.h"

/* USER CODE BEGIN Includes */
#include "usbd_cdc_if.h"
#include "usbd_cdc.h"
#include "bm71_driver.h"
#include "usb_vcp.h"
//#include "adxl345.h"
//#include "sensor.h"

/* USER CODE END Includes */

/* USER CODE BEGIN PD */

/* Defines ADXL345 SPI */
#define ADXL345_SPI             hspi1
#define ADXL345_CS_GPIO         GPIOA
#define ADXL345_CS_PIN          GPIO_PIN_4        // Change avec ta broche ACC_nCS
#define ADXL345_READ_BIT        0x80
#define ADXL345_MULTIBYTE_BIT   0x40
#define REG_DATA_FORMAT			0x31

/* ADXL345 SPI commands */
#define MULTI_BIT           0x40

/* Registres importants */
#define REG_DEVID               0x00
#define REG_DATA_FORMAT         0x31
#define REG_POWER_CTL           0x2D
#define REG_THRESH_TAP          0x1D
#define REG_DUR                 0x21
#define REG_TAP_AXES            0x2A
#define REG_INT_ENABLE          0x2E
#define REG_INT_MAP             0x2F
#define REG_INT_SOURCE          0x30

// Définition des Pin de nRST et CFG du BT
#define BM71_CFG_GPIO_Port   GPIOA
#define BM71_CFG_Pin         GPIO_PIN_10
#define BM71_nRST_GPIO_Port  GPIOC
#define BM71_nRST_Pin        GPIO_PIN_10

// mapping baudrate
#define BAUDRATE_INDEX_115200 0x05
#define BAUDRATE_INDEX_921600 0x08
/* USER CODE END PD */

/* USER CODE BEGIN PM */

/* CS control macros */
#define CS_LOW()   HAL_GPIO_WritePin(ADXL345_CS_GPIO, ADXL345_CS_PIN, GPIO_PIN_RESET)
#define CS_HIGH()  HAL_GPIO_WritePin(ADXL345_CS_GPIO, ADXL345_CS_PIN, GPIO_PIN_SET)
/* USER CODE END PM */


/* USER CODE BEGIN PV */
uint8_t adxl345_devid;

// FreeRTOS objects
QueueHandle_t ble_queue_handle;


//User Variables
/* Variables */
volatile uint8_t tap_flag = 0;
/* USER CODE END PV */

void SystemClock_Config(void);
void MX_FREERTOS_Init(void);
/* USER CODE BEGIN 0 */

// Envoyer une réponse via USB CDC
void send_response(const char *msg)
{
	CDC_Transmit_FS((uint8_t *)msg, strlen(msg));
}

void bm71_hw_init(void) //Trop spécifique à la board pour être mis dans le fichier de driver
{
	/* GPIO config */
	HAL_GPIO_WritePin(GPIOA, GPIO_PIN_10, GPIO_PIN_SET);   // P2_0 = HIGH → mode application
	HAL_GPIO_WritePin(GPIOC, GPIO_PIN_10, GPIO_PIN_SET);

	/* Reset propre */
	HAL_GPIO_WritePin(GPIOC, GPIO_PIN_10, GPIO_PIN_RESET);
	HAL_Delay(5);                                          // OK ici : HAL_Delay marche
	HAL_GPIO_WritePin(GPIOC, GPIO_PIN_10, GPIO_PIN_SET);
	HAL_Delay(50);                                        // Attente stabilisation ( datasheet = 50 ms max )
}


void USB_VCP_LauncherTask(void *argument)
{
	(void)argument;

	vTaskDelay(1000);

	/* Crée la vraie tâche qui gère le shell USB */
	if (xTaskCreate(usb_vcp_task, "USB_VCP_Shell", 1024, NULL, 5, NULL)!=pdPASS){
		usb_vcp_printf("Error Creating Task USB_VCP_Shell \r\n");
		Error_Handler();
	}

	/* Initialise la queue interne du module VCP */
	usb_vcp_init();

	/* On se suicide → plus de tâche inutile */
	vTaskDelete(NULL);
}

void BM71_LauncherTask(void *argument)
{
	bm71_t *bm = (bm71_t*)argument;

	vTaskDelay(pdMS_TO_TICKS(800));   // laisse le BM71 se réveiller

	xTaskCreate(BLEParseTask, "BM71_Parser", 768,  bm, tskIDLE_PRIORITY + 2, &bm->parser_task_handle);
	xTaskCreate(BLEShellTask,   "BM71_Shell",  512, bm, tskIDLE_PRIORITY + 4, NULL);

	vTaskDelete(NULL);
}


// Envoie une commande BLEDK3 brute
void SendCmd(uint8_t opcode, const uint8_t* data, uint8_t len)
{
	uint8_t pkt[258];
	pkt[0] = opcode;
	pkt[1] = len;
	if (len) memcpy(&pkt[2], data, len);
	HAL_UART_Transmit(&huart3, pkt, len+2, 1000);
}

// Fonction principale de configuration BM71
// Paramètres : name (ex. "MonBM71"), passkey_str (ex. "123456"), baud_index (ex. 0x05 pour 115200)
void Configurer_BM71(const char* name, const char* passkey_str, uint8_t baud_index) {
	// 1. UART en 115200 + flow control OFF (obligatoire en mode config)
	huart3.Init.BaudRate = 115200;
	huart3.Init.HwFlowCtl = UART_HWCONTROL_NONE;
	HAL_UART_DeInit(&huart3);
	HAL_UART_Init(&huart3);

	// 2. Entrée mode config
	HAL_GPIO_WritePin(BM71_CFG_GPIO_Port, BM71_CFG_Pin, GPIO_PIN_RESET);   // CFG = LOW
	HAL_GPIO_WritePin(BM71_nRST_GPIO_Port, BM71_nRST_Pin, GPIO_PIN_RESET);
	HAL_Delay(10);
	HAL_GPIO_WritePin(BM71_nRST_GPIO_Port, BM71_nRST_Pin, GPIO_PIN_SET);
	HAL_Delay(300);   // attendre boot complet

	// 3. CHANGER LE NOM → opcode 0x0D (pas 0x08, pas 0x54)
	const char* nouveau_nom = "Cattee";          // ← change ici ce que tu veux
	uint8_t payload[34];
	payload[0] = (uint8_t)strlen(nouveau_nom);
	memcpy(&payload[1], nouveau_nom, strlen(nouveau_nom));

	SendCmd(0x0D, payload, strlen(nouveau_nom) + 1);   // ← 0x0D magique
	HAL_Delay(200);

	// 4. SAUVEGARDE EN FLASH
	SendCmd(0xFF, NULL, 0);
	HAL_Delay(600);

	// 5. Sortie mode config + reset final
	HAL_GPIO_WritePin(BM71_CFG_GPIO_Port, BM71_CFG_Pin, GPIO_PIN_SET);     // CFG = HIGH
	HAL_Delay(50);
	HAL_GPIO_WritePin(BM71_nRST_GPIO_Port, BM71_nRST_Pin, GPIO_PIN_RESET);
	HAL_Delay(10);
	HAL_GPIO_WritePin(BM71_nRST_GPIO_Port, BM71_nRST_Pin, GPIO_PIN_SET);

}
static void ADXL345_Write(uint8_t reg, uint8_t val)
{
	uint8_t buf[2] = {reg, val};
	CS_LOW();
	HAL_SPI_Transmit(&ADXL345_SPI, buf, 2, HAL_MAX_DELAY);
	CS_HIGH();
}

uint8_t ADXL345_Read(uint8_t reg)
{
	uint8_t tx =  reg | ADXL345_READ_BIT;
	uint8_t rx = 0;

	CS_LOW();
	HAL_SPI_Transmit(&ADXL345_SPI, &tx, 1, 10);
	while (HAL_SPI_GetState(&ADXL345_SPI) != HAL_SPI_STATE_READY) { __NOP(); }  // safe et ultra-court
	HAL_SPI_Receive(&ADXL345_SPI, &rx, 1, 10);
 	CS_HIGH();

	return rx;
}

static void ADXL345_Init_SingleTap(void)
{
	ADXL345_Write(REG_DATA_FORMAT,  0x08);     // ±4g, full res
	ADXL345_Write(REG_THRESH_TAP,   0x35);     // ~3.3g → ajuste 0x30-0x50 selon sensibilité voulue
	ADXL345_Write(REG_DUR,          0x30);     // 30 ms max
	ADXL345_Write(0x2B,             0x00);     // Window = 0 → désactive double tap
	ADXL345_Write(REG_TAP_AXES,     0x07);     // X+Y+Z
	ADXL345_Write(REG_INT_MAP,      0x00);     // Single Tap → INT1
	ADXL345_Write(REG_INT_ENABLE,   0x40);     // active uniquement Single Tap
	ADXL345_Write(REG_DATA_FORMAT,   0x40);     // active uniquement Single Tap
	ADXL345_Write(REG_POWER_CTL,    0x08);     // mode mesure
}


/* USER CODE END 0 */

/**
  * @brief  The application entry point.
  * @retval int
  */
int main(void)
{

  /* MCU Configuration--------------------------------------------------------*/

  /* Reset of all peripherals, Initializes the Flash interface and the Systick. */
  HAL_Init();

  /* Configure the system clock */
  SystemClock_Config();

  /* Initialize all configured peripherals */
  MX_GPIO_Init();
  MX_DMA_Init();
  MX_SPI1_Init();
  MX_I2C1_Init();
  MX_TIM1_Init();
  MX_TIM2_Init();
  MX_TIM3_Init();
  MX_TIM4_Init();
  MX_USART2_UART_Init();
  MX_USART3_UART_Init();
  MX_ADC2_Init();
  MX_ADC1_Init();
  MX_TIM8_Init();
  MX_TIM7_Init();
  /* USER CODE BEGIN 2 */
	// Initialisations
	MX_USB_Device_Init();

	bm71_hw_init();

	CS_HIGH();               // nCS inactif au repos
	ADXL345_Init_SingleTap();

	//	HAL_TIM_PWM_Start(&htim4, TIM_CHANNEL_2);
	//	HAL_TIM_PWM_Stop(&htim3, TIM_CHANNEL_2);
	//	__HAL_TIM_SET_COMPARE(&htim4, TIM_CHANNEL_2, 20);


	//send_response("PWM Started\n\r");

	//	HAL_TIM_PWM_Stop(&htim4, TIM_CHANNEL_2);


	//------------------------------------------------------------
	//Initialisation des objets FreeRTOS
	//------------------------------------------------------------
	//	ble_queue_handle = xQueueCreate(32, sizeof(bm71_event_t));
	//
	//	bm71_t *bm = bm71_create(&huart3, ble_queue_handle);
	//	bm71_start(bm);           // ← tout part tout seul : parser + shell

	//	QueueHandle_t robotEvents = xQueueCreate(16, sizeof(RobotEvent_t));

	//------------------------------------------------------------
	//Initialisation des handles
	//------------------------------------------------------------
	//	sensors = Sensors_Create(
	//	        g_adxl,                     // ton handle ADXL345
	//	        tof_fl, tof_fr, tof_rl, tof_rr,   // tes 4 handles VL53Lxx
	//	        robotEvents
	//	    );
	//
	//	    Sensors_StartTask(sensors, 5);   // priorité très haute
	//
	//------------------------------------------------------------
	//Création des Taches FreeRTOS
	//------------------------------------------------------------

	/* Accelerometre */
	//	if(xTaskCreate(SensorTask,  "Sensor", 256, robotEvents , 5, NULL) != pdPASS){
	//		Error_Handler();
	//	}

	/* Module BLE */
	//		if(xTaskCreate(BM71_LauncherTask,  "BM71_Launch", 256, bm, 5, NULL)!=pdPASS){
	//			Error_Handler();
	//		}
	/* VCP USB */
			if(xTaskCreate(USB_VCP_LauncherTask, "VCP_Launch", 256, NULL, 7, NULL)!=pdPASS){
				Error_Handler();
			}

	vTaskStartScheduler();
  /* USER CODE END 2 */

  /* Call init function for freertos objects (in cmsis_os2.c) */
  MX_FREERTOS_Init();

  /* Start scheduler */
  osKernelStart();

  /* We should never get here as control is now taken by the scheduler */

  /* Infinite loop */
  /* USER CODE BEGIN WHILE */
	while (1)
	{
    /* USER CODE END WHILE */

    /* USER CODE BEGIN 3 */
	}
  /* USER CODE END 3 */
}

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
/* USER CODE BEGIN 4 */
void HAL_GPIO_EXTI_Callback(uint16_t GPIO_Pin)
{
	if (GPIO_Pin == ACC_INT1_Pin)
		{
		HAL_GPIO_WritePin(GPIOC, GPIO_PIN_10, GPIO_PIN_RESET);
		}
}
/* USER CODE END 4 */

/**
  * @brief  Period elapsed callback in non blocking mode
  * @note   This function is called  when TIM6 interrupt took place, inside
  * HAL_TIM_IRQHandler(). It makes a direct call to HAL_IncTick() to increment
  * a global variable "uwTick" used as application time base.
  * @param  htim : TIM handle
  * @retval None
  */
void HAL_TIM_PeriodElapsedCallback(TIM_HandleTypeDef *htim)
{
  if (htim->Instance == TIM6)
  {
    HAL_IncTick();
  }
}

/**
  * @brief  This function is executed in case of error occurrence.
  * @retval None
  */
void Error_Handler(void)
{
  /* USER CODE BEGIN Error_Handler_Debug */
	/* User can add his own implementation to report the HAL error return state */
	__disable_irq();
	while (1)
	{
	}
  /* USER CODE END Error_Handler_Debug */
}
#ifdef USE_FULL_ASSERT
/**
  * @brief  Reports the name of the source file and the source line number
  *         where the assert_param error has occurred.
  * @param  file: pointer to the source file name
  * @param  line: assert_param error line source number
  * @retval None
  */
void assert_failed(uint8_t *file, uint32_t line)
{
  /* USER CODE BEGIN 6 */
	/* User can add his own implementation to report the file name and line number,
     ex: printf("Wrong parameters value: file %s on line %d\r\n", file, line) */
  /* USER CODE END 6 */
}
#endif /* USE_FULL_ASSERT */

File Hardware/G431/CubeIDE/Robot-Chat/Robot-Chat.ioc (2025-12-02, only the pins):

Mcu.UserName=STM32G431CBUx
PA0.GPIO_Label=ENC1_A
PA0.Signal=S_TIM2_CH1
PA1.GPIO_Label=ENC1_B
PA1.Signal=S_TIM2_CH2
PA10.GPIO_Label=BT_Config
PA10.Signal=GPIO_Output
PA11.Signal=USB_DM
PA12.Signal=USB_DP
PA13.Signal=SYS_JTMS-SWDIO
PA14.Signal=SYS_JTCK-SWCLK
PA15.Signal=USART2_RX
PA2.Signal=USART2_TX
PA3.GPIO_Label=MOT1_Imes
PA3.Signal=ADC1_IN4
PA4.GPIO_Label=ACC_nCS
PA4.Signal=GPIO_Output
PA5.Signal=SPI1_SCK
PA6.GPIO_Label=MOT2_FW
PA6.Signal=S_TIM3_CH1
PA7.Signal=SPI1_MOSI
PA8.GPIO_Label=ENC2_B
PA8.Signal=S_TIM1_CH1
PA9.GPIO_Label=ENC2_A
PA9.Signal=S_TIM1_CH2
PB0.GPIO_Label=ACC_INT2
PB0.Signal=GPXTI0
PB1.GPIO_Label=MOT2_REV
PB1.Signal=S_TIM3_CH4
PB10.Signal=USART3_TX
PB11.Signal=USART3_RX
PB13.Signal=USART3_CTS
PB14.Signal=USART3_RTS
PB2.GPIO_Label=MOT2_Imes
PB2.Signal=ADC2_IN12
PB3.Signal=SYS_JTDO-SWO
PB5.GPIO_Label=MOT1_REV
PB5.Signal=S_TIM3_CH2
PB6.GPIO_Label=Lidar_Speed_PWM
PB6.Signal=S_TIM8_CH1
PB7.GPIO_Label=MOT1_FW\!
PB7.Signal=S_TIM4_CH2
PB8-BOOT0.Signal=I2C1_SCL
PB9.Signal=I2C1_SDA
PC10.GPIO_Label=BT_nRST
PC10.Signal=GPIO_Output
PC13.GPIO_Label=ToF_nRST
PC13.Signal=GPIO_Output
PC4.GPIO_Label=ACC_INT1
PC4.Signal=GPXTI4
PF0-OSC_IN.Signal=RCC_OSC_IN
PF1-OSC_OUT.Signal=RCC_OSC_OUT

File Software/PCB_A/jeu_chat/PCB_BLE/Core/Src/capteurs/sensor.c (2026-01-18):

/*
 * sensor.c
 *
 * Created on: Oct 28, 2025
 * Author: louisvoz
 */

#include "main.h"
#include "capteurs/sensor.h"
#include "cmsis_os.h"

/* Handles externes */
extern ADC_HandleTypeDef hadc1;
extern I2C_HandleTypeDef hi2c1;

extern uint8_t int_source;

/* Adresses et Registres ADXL343 */
#define ADXL343_ADDR            (0x53 << 1) // 0xA6
#define ADXL343_DEVID_VALUE     0xE5
#define ADXL343_REG_DEVID       0x00
#define ADXL343_REG_BW_RATE     0x2C
#define ADXL343_REG_POWERCTL    0x2D
#define ADXL343_REG_DATA_FORMAT 0x31
#define ADXL343_REG_DATAX0      0x32

#define ADXL343_REG_INT_SOURCE    0x30

/* Paramètres Tap */
#define ADXL343_THRESH_TAP      0x7F
#define ADXL343_DUR             0x7F
#define ADXL343_LATENT          0x00
#define ADXL343_TAP_AXES        0b00001110

/* Adresse TCA9548A (Multiplexeur I2C) */
#define TCA9548A_ADDR           (0x70 << 1)

/* Constantes calcul */
#define ALPHA 0.05f
#define ADXL343_MG2G_MULTIPLIER 0.0039f

/* Prototype interne (pour éviter warning implicit declaration) */
HAL_StatusTypeDef ADXL343_EnableSingleTap(void);


/* ========================================================================== */
/* ADC                                     */
/* ========================================================================== */

void INIT_ADC(uint16_t *adc_buffer, uint16_t size)
{
	if (HAL_ADCEx_Calibration_Start(&hadc1, ADC_SINGLE_ENDED) != HAL_OK)
	{
		Error_Handler();
	}
	// Correction du warning de pointeur ici : (uint32_t*)
	HAL_ADC_Start_DMA(&hadc1, (uint32_t*)adc_buffer, size);
}

// Fonction purement mathématique (plus d'appel I2C ici)
void UPDATE_V_I(Measure *m1, uint16_t *adc_buffer)
{
	float raw_courant = (float)adc_buffer[0];
	float raw_tension = (float)adc_buffer[1];

	const float k_tension = (3.3f / 4095.0f) * 3.0f;
	const float k_courant = (3.3f / 4095.0f) * 2.0f;

	m1->tension = ALPHA * (raw_tension * k_tension) + (1.0f - ALPHA) * m1->tension;
	m1->courant = ALPHA * (raw_courant * k_courant) + (1.0f - ALPHA) * m1->courant;
}

/* ========================================================================== */
/* ADXL343                                   */
/* ========================================================================== */

HAL_StatusTypeDef ADXL343_WriteReg(uint8_t reg, uint8_t value)
{
	return HAL_I2C_Mem_Write(&hi2c1, ADXL343_ADDR, reg,
			I2C_MEMADD_SIZE_8BIT, &value, 1, HAL_MAX_DELAY);
}

HAL_StatusTypeDef ADXL343_ReadReg(uint8_t reg, uint8_t *value)
{
	return HAL_I2C_Mem_Read(&hi2c1, ADXL343_ADDR, reg,
			I2C_MEMADD_SIZE_8BIT, value, 1, HAL_MAX_DELAY);
}

HAL_StatusTypeDef ADXL343_ReadMulti(uint8_t reg, uint8_t *buffer, uint16_t size)
{
	return HAL_I2C_Mem_Read(&hi2c1, ADXL343_ADDR, reg,
			I2C_MEMADD_SIZE_8BIT, buffer, size, HAL_MAX_DELAY);
}

HAL_StatusTypeDef ADXL343_EnableSingleTap(void)
{
	if (ADXL343_WriteReg(0x1D, ADXL343_THRESH_TAP) != HAL_OK) return HAL_ERROR;
	if (ADXL343_WriteReg(0x21, ADXL343_DUR) != HAL_OK) return HAL_ERROR;
	if (ADXL343_WriteReg(0x22, ADXL343_LATENT) != HAL_OK) return HAL_ERROR;
	if (ADXL343_WriteReg(0x2A, ADXL343_TAP_AXES) != HAL_OK) return HAL_ERROR;
	if (ADXL343_WriteReg(0x2E, 0x40) != HAL_OK) return HAL_ERROR; // Enable Single Tap INT
	if (ADXL343_WriteReg(0x2F, 0x00) != HAL_OK) return HAL_ERROR; // Map to INT1

	return HAL_OK;
}

HAL_StatusTypeDef ADXL343_Init(void)
{
	uint8_t id = 0;

	if (HAL_I2C_IsDeviceReady(&hi2c1, ADXL343_ADDR, 3, 100) != HAL_OK)
	{
		return HAL_ERROR;
	}

	if (ADXL343_ReadReg(ADXL343_REG_DEVID, &id) != HAL_OK) return HAL_ERROR;
	if (id != ADXL343_DEVID_VALUE) return HAL_ERROR;

	if (ADXL343_WriteReg(ADXL343_REG_POWERCTL, 0x00) != HAL_OK) return HAL_ERROR;
	if (ADXL343_WriteReg(ADXL343_REG_DATA_FORMAT, 0x08) != HAL_OK) return HAL_ERROR;
	if (ADXL343_WriteReg(ADXL343_REG_BW_RATE, 0x0A) != HAL_OK) return HAL_ERROR;
	if (ADXL343_WriteReg(ADXL343_REG_POWERCTL, 0x08) != HAL_OK) return HAL_ERROR;

	if (ADXL343_EnableSingleTap() != HAL_OK) return HAL_ERROR;

	// Lecture pour effacer les flags initiaux
	uint8_t source;
	ADXL343_ReadReg(0x30, &source);


	return HAL_OK;
}

HAL_StatusTypeDef ADXL343_ReadXYZ(Measure *m1)
{
	uint8_t buffer[6];
	int16_t rawX, rawY, rawZ;
	uint8_t INT;

	if (ADXL343_ReadMulti(ADXL343_REG_DATAX0, buffer, 6) != HAL_OK)
		return HAL_ERROR;

	// Note: Ecriture/Lecture du registre INT_MAP (0x2F) ici - logique spécifique conservée
	ADXL343_WriteReg(0x2F, 0b10111111);
	if (ADXL343_ReadReg(0x2F, &INT) != HAL_OK)
		return HAL_ERROR;

	rawX = (int16_t)((buffer[1] << 8) | buffer[0]);
	rawY = (int16_t)((buffer[3] << 8) | buffer[2]);
	rawZ = (int16_t)((buffer[5] << 8) | buffer[4]);

	m1->A_X = ALPHA * (rawX * ADXL343_MG2G_MULTIPLIER) + m1->A_X * (1 - ALPHA);
	m1->A_Y = ALPHA * (rawY * ADXL343_MG2G_MULTIPLIER) + m1->A_Y * (1 - ALPHA);
	m1->A_Z = ALPHA * (rawZ * ADXL343_MG2G_MULTIPLIER) + m1->A_Z * (1 - ALPHA);

	return HAL_OK;
}

/* ========================================================================== */
/* ToF                                 */
/* ========================================================================== */
//void ToF_Init(ToF_t *tof){
//	tof->left= -1;
//	tof->right = -1;
//	tof->front = -1;
//	tof->back = -1;
//	tof->vl53l0x_initialized = false;

//	I2C_ResetBus(&(tof->i2c));

//	if (initVL53L0X(1, &(tof->i2c)))
//	{
//		setSignalRateLimit(0.25f);
//		setVcselPulsePeriod(VcselPeriodPreRange, 10);
//		setVcselPulsePeriod(VcselPeriodFinalRange, 14);
//		setMeasurementTimingBudget(300000UL);
//		tof->vl53l0x_initialized = true;
//	}

//}

/* ========================================================================== */
/* I2C UTILS                                   */
/* ========================================================================== */

void I2C_ResetBus(I2C_HandleTypeDef *hi2c)
{
	GPIO_InitTypeDef GPIO_InitStruct = {0};

	__HAL_I2C_DISABLE(hi2c);
	HAL_I2C_DeInit(hi2c);

	GPIO_InitStruct.Pin = GPIO_PIN_8 | GPIO_PIN_9;
	GPIO_InitStruct.Mode = GPIO_MODE_OUTPUT_OD;
	GPIO_InitStruct.Pull = GPIO_PULLUP;
	GPIO_InitStruct.Speed = GPIO_SPEED_FREQ_LOW;
	HAL_GPIO_Init(GPIOB, &GPIO_InitStruct);

	for (int i = 0; i < 10; i++)
	{
		HAL_GPIO_WritePin(GPIOB, GPIO_PIN_8, GPIO_PIN_SET);
		osDelay(1);
		HAL_GPIO_WritePin(GPIOB, GPIO_PIN_8, GPIO_PIN_RESET);
		osDelay(1);
	}

	HAL_GPIO_WritePin(GPIOB, GPIO_PIN_8 | GPIO_PIN_9, GPIO_PIN_SET);

	GPIO_InitStruct.Pin = GPIO_PIN_8 | GPIO_PIN_9;
	GPIO_InitStruct.Mode = GPIO_MODE_AF_OD;
	GPIO_InitStruct.Pull = GPIO_PULLUP;
	GPIO_InitStruct.Speed = GPIO_SPEED_FREQ_LOW;
	GPIO_InitStruct.Alternate = GPIO_AF4_I2C1;
	HAL_GPIO_Init(GPIOB, &GPIO_InitStruct);

	HAL_I2C_Init(hi2c);
	__HAL_I2C_ENABLE(hi2c);
}

void check_single_tap(uint8_t * ret){
	ADXL343_ReadReg(ADXL343_REG_INT_SOURCE, ret);
}

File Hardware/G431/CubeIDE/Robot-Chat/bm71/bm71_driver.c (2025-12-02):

/* bm71_driver.c */
#include "bm71_driver.h"
#include "cmsis_os.h"
#include <string.h>
#include "stdio.h"

static bm71_t *g_bm = NULL;

static uint8_t calc_checksum(const uint8_t *data, uint16_t len)
{
	uint8_t sum = 0;
	for (uint16_t i = 0; i < len; i++) sum += data[i];
	return (uint8_t)(0x100 - sum);
}

static void start_rx_dma(bm71_t *bm)
{
	HAL_UART_Receive_DMA(bm->huart, bm->rx_dma_buf, BM71_RX_BUF_SIZE);
	__HAL_DMA_DISABLE_IT(bm->huart->hdmarx, DMA_IT_HT);
}

static void post_event(bm71_t *bm, bm71_event_type_t type, const uint8_t *data, uint16_t len)
{
	bm71_event_t evt = { .type = type, .len = len };
	if (len && data) {
		uint16_t cp = (len > BM71_MAX_PACKET_LEN) ? BM71_MAX_PACKET_LEN : len;
		memcpy(evt.data, data, cp);
	}
	xQueueSendFromISR(bm->event_queue, &evt, NULL);   // Safe from ISR
}

/* Tâche parser – priorité très basse */
void BLEParseTask(void *arg)
{
	bm71_t *bm = (bm71_t*)arg;
	uint8_t pkt[BM71_MAX_PACKET_LEN + 10];
	uint16_t pos = 0;

	for (;;) {
		ulTaskNotifyTake(pdTRUE, portMAX_DELAY);   // Attente notification depuis ISR

		uint16_t tail = BM71_RX_BUF_SIZE - __HAL_DMA_GET_COUNTER(bm->huart->hdmarx);

		while (bm->rx_head != tail) {
			uint8_t c = bm->rx_dma_buf[bm->rx_head];
			bm->rx_head = (bm->rx_head + 1) % BM71_RX_BUF_SIZE;

			if (bm->transparent_mode) {
				/* Détection trame cachée */
				if (c == 0xAA && pos == 0) {
					pkt[pos++] = c;
					continue;
				}
				if (pos > 0) {
					pkt[pos++] = c;
					if (pos >= 4) {
						uint16_t pkt_len = (pkt[1] << 8) | pkt[2];
						if (pos >= pkt_len + 1) {
							if (calc_checksum(&pkt[1], pkt_len) == pkt[pkt_len]) {
								post_event(bm, BM71_EVT_HIDDEN_COMMAND, pkt + 3, pkt_len - 2);
							}
							pos = 0;
						}
						if (pos >= sizeof(pkt)) pos = 0;
					}
				} else {
					post_event(bm, BM71_EVT_RAW_DATA, &c, 1);
				}
			} else {
				/* Mode commande au boot */
				if (c == 0xAA && pos == 0) pkt[pos++] = c;
				else if (pos > 0) {
					pkt[pos++] = c;
					if (pos >= 4) {
						uint16_t pkt_len = (pkt[1] << 8) | pkt[2];
						if (pos >= pkt_len + 1 && calc_checksum(&pkt[1], pkt_len) == pkt[pkt_len]) {
							uint8_t opcode = pkt[3];
							if (opcode == 0x71) { bm->connected = true;  post_event(bm, BM71_EVT_CONNECTED, NULL, 0); }
							if (opcode == 0x72) { bm->connected = false; post_event(bm, BM71_EVT_DISCONNECTED, NULL, 0); }
						}
						pos = 0;
					}
				}
			}
		}
	}
}

/* ISR DMA */
void HAL_UART_RxCpltCallback(UART_HandleTypeDef *huart)
{
	if (g_bm && huart == g_bm->huart && g_bm->parser_task_handle) {
		BaseType_t xHigherPriorityTaskWoken = pdFALSE;
		vTaskNotifyGiveFromISR(g_bm->parser_task_handle, &xHigherPriorityTaskWoken);
		portYIELD_FROM_ISR(xHigherPriorityTaskWoken);
	}
}

/* API */
bm71_t* bm71_create(UART_HandleTypeDef *huart, QueueHandle_t queue)
{
	static bm71_t bm = {0};
	bm.huart = huart;
	bm.event_queue = queue;
	g_bm = &bm;
	return &bm;
}

int bm71_write(bm71_t *bm, const uint8_t *data, uint16_t len)
{
	return (HAL_UART_Transmit_DMA(bm->huart, (uint8_t*)data, len) == HAL_OK) ? len : 0;
}

int bm71_send_hidden_cmd(bm71_t *bm, uint8_t opcode, const uint8_t *params, uint16_t len)
{
	uint8_t pkt[BM71_MAX_PACKET_LEN + 5];
	uint16_t total = 3 + len;
	pkt[0] = 0xAA;
	pkt[1] = total >> 8;
	pkt[2] = total & 0xFF;
	pkt[3] = opcode;
	if (len) memcpy(&pkt[4], params, len);
	pkt[4 + len] = calc_checksum(&pkt[1], total);
	return bm71_write(bm, pkt, total + 2);
}



/* ===================================================================
   Tâche shell intégrée au driver – plus jamais besoin de pointeur !
   =================================================================== */
void BLEShellTask(void *argument)
{
    bm71_t *bm = (bm71_t*)argument;

    char line[160];           // ← 160 au lieu de 128 = marge de sécurité
    uint16_t pos = 0;
    bm71_event_t evt;

    // Message de bienvenue au boot (facultatif)
    vTaskDelay(pdMS_TO_TICKS(1000));
    bm71_write(bm, (uint8_t*)"\r\n\r\n*** G431-BLE Shell v1.0 ***\r\n> ", 37);

    for(;;)  // ← BOUCLE INFINIE OBLIGATOIRE
    {
        if (xQueueReceive(bm->event_queue, &evt, pdMS_TO_TICKS(1000)) == pdPASS)
        {
            if (evt.type == BM71_EVT_CONNECTED)
            {
                bm71_write(bm, (uint8_t*)"\r\n*** CONNECTED ***\r\n> ", 23);
                pos = 0;
            }
            else if (evt.type == BM71_EVT_RAW_DATA)
            {
                for (uint16_t i = 0; i < evt.len; i++)
                {
                    char c = evt.data[i];

                    if (c == '\r' || c == '\n')
                    {
                        if (pos == 0) continue;
                        line[pos] = '\0';

                        bm71_write(bm, (uint8_t*)"\r\n", 2);

                        if (strcmp(line, "reboot") == 0)
                        {
                            bm71_write(bm, (uint8_t*)"Bye !\r\n", 7);
                            vTaskDelay(200);
                            NVIC_SystemReset();
                        }
                        else if (strcmp(line, "help") == 0)
                        {
                            bm71_write(bm, (uint8_t*)"uptime  reboot  help\r\n> ", 23);
                        }
                        else
                        {
                            bm71_write(bm, (uint8_t*)"OK\r\n> ", 6);
                        }
                        pos = 0;
                    }
                    else if ((c == 8 || c == 127) && pos > 0)
                    {
                        pos--;
                        bm71_write(bm, (uint8_t*)"\b \b", 3);
                    }
                    else if (c >= 32 && c <= 126 && pos < sizeof(line)-1)
                    {
                        line[pos++] = c;
                        bm71_write(bm, (uint8_t*)&c, 1);
                    }
                }
            }
        }
        else
        {
            // timeout toutes les secondes → juste pour garder la tâche vivante
            // rien à faire
        }
    }
    // ← NE JAMAIS ARRIVER ICI
    // vTaskDelete(NULL);  ← À SUPPRIMER SI TU L’AVAIS MIS !
}

void bm71_start(bm71_t *bm)
{
	start_rx_dma(bm);

	/* Reset logiciel du BM71 */
	bm71_send_hidden_cmd(bm, 0x02, NULL, 0);

	/* Active transparent + adv (commandes envoyées tout de suite) */
	uint8_t trans[] = {0x0C, 0x01};
	bm71_send_hidden_cmd(bm, 0x40, trans, 2);
	uint8_t adv[] = {0x01};
	bm71_send_hidden_cmd(bm, 0x1C, adv, 1);

	bm->transparent_mode = true;
}

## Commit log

2025-09-09 Creation du KiCad
    [projet-chat-ese.kicad_pcb, projet-chat-ese.kicad_sch]
2025-09-12 [Update] PCB
    [MCU.kicad_sch, Power.kicad_sch, ToF.kicad_sch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]
2025-09-19 KSA : PCB G431 :
    [BT_Module.kicad_sch, ToF.kicad_sch, accelerometer.kicad_sch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]
2025-09-24 On a pas de wiork trtee anyway
    [MCU.kicad_sch, ToF.kicad_sch, motor.kicad_sch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]
2025-09-24 MAJ PCB
    [Main_Board-B_Cu.gbr, Main_Board-B_Mask.gbr, Main_Board-B_Paste.gbr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]
2025-09-25 Finishing PCB
    [MCU.kicad_sch, motor.kicad_sch, projet-chat-ese.kicad_pcb]
2025-09-25 PCB G431 details
    [projet-chat-ese.kicad_pcb]
2025-09-27 code STM Bluetooth envoie et réception de données
2025-09-29 MODIF PCB ( NEW TIMER )
    [Main_Board-B_Cu.gbr, Main_Board-B_Mask.gbr, Main_Board-B_Paste.gbr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]
2025-09-30 code STM Bluetooth envoie et réception de données et scanf
2025-09-30 Test ACCelero
    [projet-chat-ese.kicad_pcb]
2025-10-01 MAJ FOLDER
    [I2C.kicad_sch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]
2025-10-01 Updating silkscreen on pcb
    [projet-chat-ese.kicad_pcb]
2025-10-01 check pcb kenny LF
    [BT_Module.kicad_sch, MCU.kicad_sch, accelerometer.kicad_sch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]
2025-10-01 Last PCB edits G431
    [MCU.kicad_sch, ToF.kicad_sch, projet-chat-ese.kicad_pcb]
2025-10-01 G431 PCB Final
2025-10-01 code STM32WB communication avec un pc
2025-10-01 CODE LIDAR
2025-11-12 freertos code + driver
2025-11-12 separataion des .c .h
2025-11-26 Kenny's Last work
    [MCU.kicad_sch, motor.kicad_sch, projet-chat-ese.csv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]
2025-12-02 update lidar
2025-12-05 PID corrigé
2025-12-09 Structure de taches
2025-12-10 editing odometry data
2025-12-10 schematic update
    [I2C.kicad_sch, Main_Board.kicad_sch, Motor_drivers.kicad_sch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]
2025-12-11 update tof + lidar
2026-01-18 updating PCB documentations
    [BOM.csv, BT_Module.kicad_sch, I2C.kicad_sch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]
2026-01-22 Enhance README with PCB Bluetooth details
    Added detailed information about the PCB Bluetooth components and features.
2026-01-23 Tidyinn up the readme
    Removed the 'Schéma de Principe' section from the README.
2026-01-23 Update README with principle diagram and images
    Added principle diagram and PCB realization images.
2026-01-23 Update README with decision flowchart and sensor info
    Added decision flowchart and updated sensor and actuator sections.

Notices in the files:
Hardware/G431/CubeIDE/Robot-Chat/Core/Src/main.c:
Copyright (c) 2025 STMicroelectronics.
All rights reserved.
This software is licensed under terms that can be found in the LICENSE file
